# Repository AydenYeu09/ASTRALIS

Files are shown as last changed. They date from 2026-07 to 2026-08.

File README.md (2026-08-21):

# ASTRALIS

**ASTRALIS** is a thrust-vectoring aerial manipulation research quadcopter designed to investigate how independently vectored thrust can compensate for disturbances induced by the movement of an onboard robotic arm. 

ASTRALISv2_2026-Aug-08_04-18-19AM-000_CustomizedView49024496437

[ASTRALIS Public Onshape](https://cad.onshape.com/documents/e7aa6cff1a0b3da1907f913a/w/77e9de90cc715c4e64e50337/e/d9e24aa74ee5dafe20d41019)

## Research Goals
Aerial manipulators, while adding functionality and expanding the applicable scope of a quadcopter, introduce a major problem to multirotor flight: moving an arm and payload changes the vehicle's mass distribution and produces additional forces and moments on the aircraft. 
Conventional quadcopter s attempt to compensate for these disturbances primarily by changing the thrust produced by each motor. ASTRALIS adds another control input by allowing the motors themselves to tilt and change the direction of their thrust. 
The primary question I want to investigate is:
> **To what extent can independently vectored thrust reduced attitude disturbances caused by the movement of an aerial manipulator and its payload?**
ASTRALIS is designed specifically as a testbed to investigate this question through repeatable arm-disturbance experiments during flight.
---
## Design
ASTRALIS consists of three main subsystems: 
- A custom quadcopter airframe (carbon fiber machined top and bottom plates + cf nylon frame pieces)
- Four independently tilting motor pods
- A multi-jointed robotic manipulator

A **Pixhawk 6C Mini** handles flight control and stabilization, while a **Raspberry Pi 4 Model B** acts as the companion computer for running and logging experimental routines, telemetry collection, and future software uses.

### Thrust-Vectoring Pods
Each motor is mounted to a tilting pod actuated by a servo and pushrod linkage. This allows the direction of each motor's thrust to be changed independently. The current design establishes the pod pivot, servo type and location, and general linkage architecture. The final linkage dimensions, ball-end selection, and mechanical advantage calculations will be determined through physical prototyping. 

ASTRALISv2_2026-Aug-09_10-05-22PM-000_CustomizedView5219588414
ASTRALISv2_2026-Aug-09_10-07-08PM-000_CustomizedView10570838011_png

The design includes a dual flange-bearing supported pivot and shoulder bolt, mechanically linked by a threaded rod to a servo horn. This was chosen because the turning drone's motors during thrust action will induce gyroscopic force, and I want to ensure that the system is structurally sound. The mounts will be printed out of Nylon CF as it is the strongest available filament in my collection. 

### Aerial Manipulator 
ASTRALIS uses a multi-jointed robotic arm to manipulate payloads and generate controlled disturbances during flight. The arm is designed to use **Waveshare ST3215 serial bus servos**, allowing multiple joints to be controlled through the same communication bus. 
The arm was originally designed around DYNAMIXEL servos but was redesigned around the ST3215 to increase available torque while reducing the overall costs of the actuator and control system. 

>**Note: The arm will be 3D printed out of PLA**

ASTRALISv2_2026-Aug-09_10-07-26PM-000_CustomizedView5861968826_png

Payload capacity is being estimated by calculating the torque produced by each arm component and payload about its respective joints.



The calculated payload limits will be estimated once hardware is confirmed. 

---
## Electronics



The electronics are spread across flight control and experiment control. 

| Component | Details |
|---|---|
| Pixhawk 6C Mini | Main flight controller |
| Raspberry Pi 5 | Companion computer used for experimental control |
| M10 GPS  | Vehicle positioning |
| Pi Camera | Used for object pickup and capturing on-board footage |
| ST3215 Servos | Used for Robotic Arm  |
| PCA9685 | Tilt Servo Driver Board | 
| DS3230 | High Torque Tilt Servos (picked to handle gyroscopic forces from tilting the motors) |
| Hobbywing XRotor 3110 900KV | Thrust Motors |
| Blueson A2 4in1 65A ESC | ESC for XRotor 3110s|

---
## Software (derived from discontinued Urban-Gust-Optimized UAV) 
Software development is currently focused on establishing basic communication between the Raspberry Pi and the Pixhawk and building the framework required for arm-disturbance experiments. Once I have the hardware confirmed, I will delve into system-
Current code includes: 
- MAVLink initialization
- Heartbeat monitoring
- Vehicle State tracking
- Attitude and angular-rate data
- Battery telemetry
- GPS telemetry

Several of the modules are still under development and will be implemented as the corresponding hardware becomes available/confirmed for purchase.

---
## Experimental Plan
>**The following experiment is the current plan, but is subject to subtle changes as hardware is confirmed for purchase or rejected**

The initial experiment will measure the aircraft's response to repeatable robotic-arm movements. A standardized payload will be picked up by the manipulator and moved through a predetermined trajectory while vehicle telemetry is recorded.
Tests will eventually be performed for both **with and without thrust-vectoring compensation**.

After the results of this experiment, I will develop a prediction-based model in MATLAB that will account for non-predetermined arm movements. 

## Future Plans 
After determining the impact of thrust-vectoring vehicle stability, I plan to add more software capabilities to the drone, making it a fully fledged UAV. I want to explore more into computer vision driven tasks with the manipulator.

Measurements will include:
- Peak roll and pitch deviation
- RMS attitude error
- Angular velocity
- Settling time 
- Response across different payload masses 

This will allow the performance of the thrust-vectoring system to be compared against the aircraft's baseline performance.

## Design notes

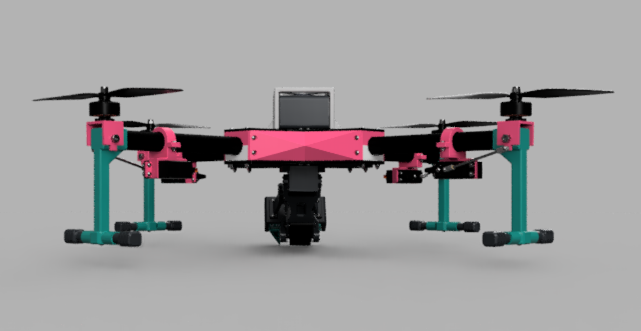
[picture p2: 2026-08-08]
Renders/Astralis_backRender.png

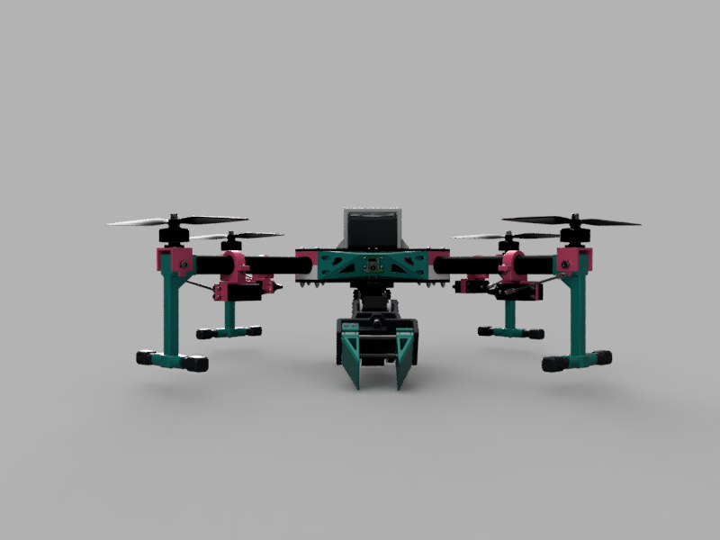
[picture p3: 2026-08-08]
Renders/Astralis_frontRender.png

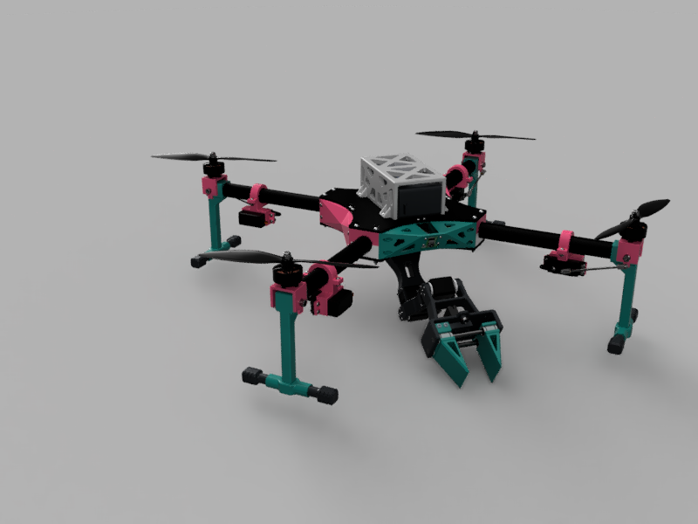
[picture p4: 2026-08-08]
Renders/Astralis_leftIso.png

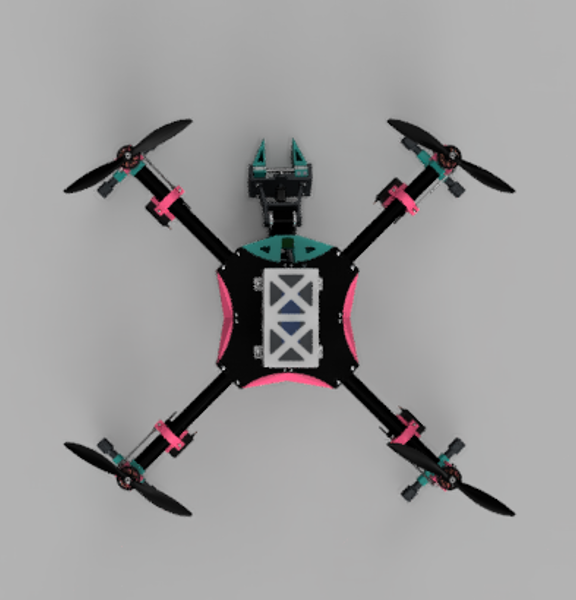
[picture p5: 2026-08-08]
Renders/Astralis_topRender.png

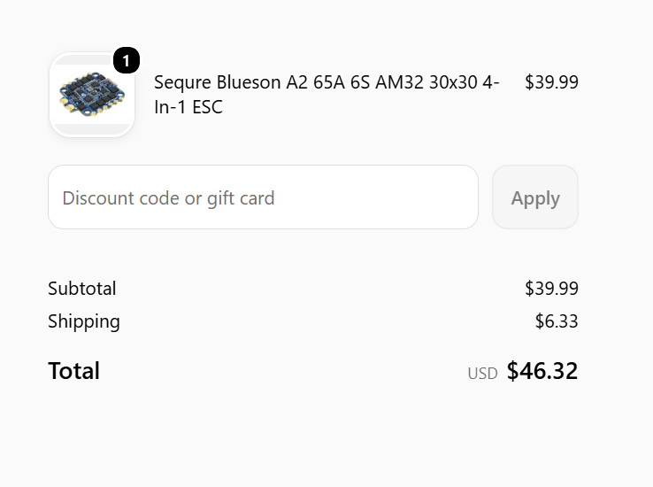
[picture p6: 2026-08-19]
Cart Shipping Screenshots/defiancerc.png

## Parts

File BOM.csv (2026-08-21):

Item | Category | Qty | Unit cost | Total cost | Vendor | Link | Status | Notes
Raspberry Pi 4 Model B | General Electronics | 1 | $0.00 | 0 | Raspberry Pi | https://www.raspberrypi.com/products/raspberry-pi-4-model-b/ | Already Owned | Already Owned
Pixhawk 6C Mini + PM06 | General Electronics | 1 | $0.00 | 0 | Holybro | https://holybro.com/products/pixhawk-6c-mini?variant=44511519539389 | Already Owned | flight controller, ease of access to telemetry, good interconnectivity with 4in1 esc, servo PWMS can connect to it
Sequre Blueson A2 65A 4in1 ESC | General Electronics | 1 | $39.99 | 39.99 | DefianceRC | https://www.defiancerc.com/collections/electronic-speed-control/products/sequre-blueson-a2-65a-6s-am32-4-in-1-esc | To buy
Ovonic Roam Series 6S Lipo Battery 6000mAh 6S1P 150C 22.2V Long Range Lipo Battery with XT90-S Anti Spark Plug for 7-10 inch Cinelifter Multirotor X-Class FPV Drone | General Electronics | 1 | $59.99 | 59.99 | OVONIC USA | https://us.ovonicshop.com/products/ovonic-roam-series-6s-lipo-battery-5500mah-6s1p-150c-22-2v-long-range-lipo-battery-with-xt90-s-anti-spark-plug-for-6s-cinel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 | To buy | factoring in $5 off $50+ discount
MECCANIXITY 304 Stainless Steel Round Rods, 6mm x 80mm Solid Shaft Rods for DIY Craft Model Car Helicopter Airplane, Pack of 5 | Aerial Manipulator | 1 | $9.99 | 9.99 | Amazon | https://www.amazon.com/MECCANIXITY-Stainless-Steel-Helicopter-Airplane/dp/B0DPH1PFTT | To buy
Pi Camera Module 3 | General Electronics | 1 | $0.00 | 0 | Amazon | https://www.amazon.com/Arducam-Raspberry-Camera-Module-IMX708/dp/B0G5YJMR8Q?sp_csd=d2lkZ2V0TmFtZT1zcF9hdGY | Already Owned
ACROPIX MR106ZZ Bearings Double Shielded Pre-Lubricated Deep Groove Ball Bearings 6x10x3mm Silver Tone - Pack of 10 | Aerial Manipulator | 1 | $7.49 | 7.49 | Amazon | https://www.amazon.com/ACROPIX-Bearings-Shielded-Pre-Lubricated-Deep-6x10x3mm/dp/B0C4PGLSCY | To buy
22mm x 20mm x 500mm Carbon Fiber Tube 2pc | Mechanical - Arm | 1 | $4.48 | 4.48 | AliExpress | https://www.aliexpress.us/item/2255800548281454.html?pdp_ext_f=%7B"order"%3A"4548"%2C"eval"%3A"1"%2C"fromPage"%3A"search"%7D&pdp_npi=6%40dis%21USD%218.80%215.10%21%21%218.80%215.10%21%402101ea8f17857353482108943e0d2f%2110000015285622328%21sea%21US%216211510477%21X%211%210%21n_tag%3A-29919%3Bd%3A782a1452%3Bm03_new_user%3A-29895%3BpisId%3A5000000212462172&curPageLogUid=WQxJ5C6ExckD&utparam-url=scene%3Asearch%7Cquery_from%3A%7Cx_object_id%3A4000734596206%7C_p_origin_prod%3A | To buy
4X DSServo Waterproof Servo (30Kg) | Rotor Tilt - Electronics | 1 | $52.78 | 52.78 | RCDrone | https://rcdrone.top/products/4x-waterproof-servo-20kg-25kg-30kg-35kg-40kg-high-speed-servo-pro-metal-gear-digital-servo-baja-servo-for-1-8-1-10-scale-rc-cars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 | To buy | MG996Rs are slower and not significantly cheaper —> having a heavier grade servo ensures that the force of gyroscopic precession won’t strip all the gears of the servo. also vendor has no shipping cost
Micro M10 GPS | General Electronics | 1 | $36.38 | 36.38 | AliExpress | https://www.aliexpress.us/item/3256807973728391.html?curPageLogUid=Nfn08dpLiBxy | To buy | Need for positioning and sensor for experiment
4PCS Hobbywing XRotor 3110/ Premium Brushless Motor - 900KV 4-6S M5 Shaft for 8-10" Heavy Lift FPV Drones | General Electronics | 1 | $81.60 | 81.6 | AliExpress | https://www.aliexpress.us/item/3256809458664696.html?pdp_ext_f=%7B"order"%3A"19"%2C"eval"%3A"1"%2C"fromPage"%3A"search"%7D&pdp_npi=6%40dis%21USD%21169.42%2183.02%21%21%211137.04%21557.15%21%402101d9ef17857369675166543e0f5f%2112000049988191307%21sea%21US%216211510477%21X%211%210%21n_tag%3A-29919%3Bd%3A782a1452%3Bm03_new_user%3A-29895&curPageLogUid=20aVGjfR1oiC&utparam-url=scene%3Asearch%7Cquery_from%3A%7Cx_object_id%3A1005009644979448%7C_p_origin_prod%3A | To buy
2pair HQProp 9x5x3 | Testing | 1 | $10.55 | 10.55 | AliExpress | https://www.aliexpress.us/item/3256808163754090.html?pdp_ext_f=%7B"order"%3A"141"%2C"eval"%3A"1"%2C"fromPage"%3A"search"%7D&pdp_npi=6%40dis%21USD%2120.23%2110.72%21%21%21135.78%2171.96%21%402101e81117857374162586296e0fc7%2112000044691697503%21sea%21US%216211510477%21X%211%210%21n_tag%3A-29919%3Bd%3Af6a29556%3Bm03_new_user%3A-29895&curPageLogUid=giSY8NM4Eluz&utparam-url=scene%3Asearch%7Cquery_from%3A%7Cx_object_id%3A1005008350068842%7C_p_origin_prod%3A | To buy
M3x8 Plastites (pk of 50) | Fasteners | 2 | $7.42 | 14.84 | McMaster | https://www.mcmaster.com/99461A941/ | To buy
M3x50mm Socket Partially Threaded | Fasteners | 1 | $5.65 | 5.65 | McMaster | https://www.mcmaster.com/91292A026/ | To buy | Arm tube clamps
M3 locknuts (pk of 100) | Fasteners | 1 | $4.29 | 4.29 | Amazon | https://www.amazon.com/Hordion-100Pcs-Stainless-Locknuts-Non-Slip/dp/B0CX16JZ6Z | To buy
Stainless Steel m4 thread, 5mm x 30mm (pk of 8) | Fasteners | 1 | $9.99 | 9.99 | Amazon | https://www.amazon.com/MECCANIXITY-Stainless-Hydraulic-Injection-Industries/dp/B0FDPX976R | To buy
MF95zz Bearing (5mm ID, 9mm OD) - pk of 10 | Fasteners | 1 | $9.49 | 9.49 | Amazon | https://www.amazon.com/uxcell-Bearing-5x9x3mm-Shielded-Bearings/dp/B085D7WFBR | To buy
Waveshare ST3215 Servo Motor | Aerial Manipulator | 4 | $20.63 | 82.52 | Waveshare | https://www.waveshare.com/st3215-servo.htm | To buy | replaced dynamixel because they are cheaper and are precise enough.
Serial Bus Servo Control/Power Distribution Board | Aerial Manipulator | 1 | $4.99 | 4.99 | Waveshare | https://www.waveshare.com/product/bus-servo-adapter-a.htm | To buy
12S to 12V BEC | General Electronics | 1 | $5.05 | 5.05 | AliExpress | https://www.aliexpress.us/item/3256810372424874.html?pdp_ext_f=%7B"order"%3A"76"%2C"eval"%3A"1"%2C"fromPage"%3A"search"%7D&pdp_npi=6%40dis%21USD%2110.87%215.00%21%21%2172.94%2133.55%21%402101c28d17861703912206676e0f36%2112000053151968418%21sea%21US%216211510477%21X%211%210%21n_tag%3A-29919%3Bd%3Af6a29556%3Bm03_new_user%3A-29895&curPageLogUid=Yly6hpUVcbog&utparam-url=scene%3Asearch%7Cquery_from%3A%7Cx_object_id%3A1005010558739626%7C_p_origin_prod%3A | To buy
8-23V Input to 5V USBC Output BEC | General Electronics | 1 | $5.50 | 5.5 | AliExpress | https://www.aliexpress.us/item/3256808480645422.html?pdp_ext_f=%7B"order"%3A"602"%2C"eval"%3A"1"%2C"fromPage"%3A"search"%7D&pdp_npi=6%40dis%21USD%2111.91%212.72%21%21%2179.95%2118.25%21%4021030dcd17861703694924828e2255%2112000046156518282%21sea%21US%216211510477%21X%211%210%21n_tag%3A-29919%3Bd%3A782a1452%3Bm03_new_user%3A-29895%3BpisId%3A5000000214368806&curPageLogUid=rfv8wqtYsREv&utparam-url=scene%3Asearch%7Cquery_from%3A%7Cx_object_id%3A1005008666960 | To buy
Step Down BEC 5V (normal output) | General Electronics | 1 | $3.24 | 3.24 | AliExpress | https://www.aliexpress.us/item/3256810580944443.html?pdp_ext_f=%7B"order"%3A"114"%2C"eval"%3A"1"%2C"fromPage"%3A"search"%7D&pdp_npi=6%40dis%21USD%217.89%213.63%21%21%2152.94%2124.35%21%402101e81117863143204767761e0eed%2112000053441881891%21sea%21US%216211510477%21X%211%210%21n_tag%3A-29919%3Bd%3A782a1452%3Bm03_new_user%3A-29895&curPageLogUid=VkQ4012PO8G6&utparam-url=scene%3Asearch%7Cquery_from%3A%7Cx_object_id%3A1005010767259195%7C_p_origin_prod%3A | To buy
 |  |  | Subtotal | 448.81
 |  |  | Total Cost (with Shipping Fees and Taxes) | 500.77

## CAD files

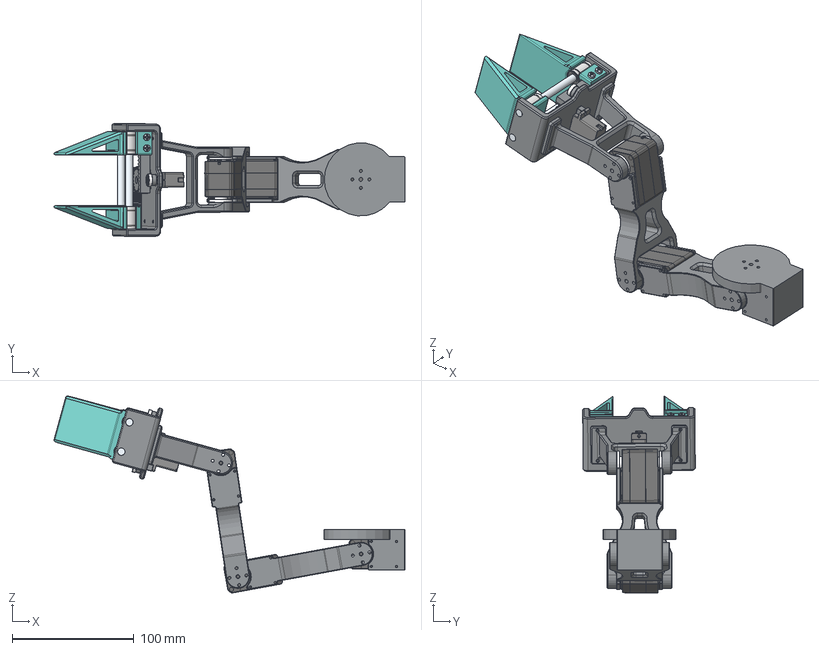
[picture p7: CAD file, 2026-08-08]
CAD Files/ASTRALIS - Arm/AARMv2.step
287.8 x 92.4 x 161.5 mm
GE_27:1__??1 x 3
SG-ZIJI_15:1__??1 x 3
???????? v2:1__??1 x 6
PCB-CHAZUO_92:1__??1 x 3
ZK_122:1__??1 x 3
MOTOR-1723_3:1__??1 x 3
XG-ZIJI_16:1__??1 x 3
wrist
base joint
Ligament 2
�г�-��ת1 x 2
Բ��2 x 2
����(Բ��)1[4] x 2
Rack (16 teeth) x 2
��ת4[2] x 2
����(Բ��)1[9] x 2
����(Բ��)1[8] x 2
����(Բ��)1[1] x 2
rod x 2
Shaft
PH Pan head screw M3x0.50 x 6 x 4
��ת2 x 2
Socket button head screw M2x0.4 x 8
main housing
����(Բ��)1[6] x 2
��ת4[1] x 2
����(Բ��)1[5] x 2
/private/var/mobile/Containers/Data/Application/CE62752C-AD6F-4AF3-94 70-06643F6F38D5/tmp/5A85296E-EDAF-43B4-99FA-8EC373BC8470.tmp x 4
����(Բ��)1[3] x 2
module x 2
����(Բ��)1[2] x 2
Spur gear (20 teeth)
����(Բ��)2 x 2
����(Բ��)1[7] x 2

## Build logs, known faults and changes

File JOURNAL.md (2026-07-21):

# Astralis: An Overactuated Aerial Manipulation Quadcopter

> **Note:** Built for Hack Club's Stardance Program and intended to serve as an MIT Maker Portfolio project.

---

# 2026-06-29 — Project Initialization

### Derived from the Urban Gust Optimized UAV Project

**Astralis** originated from my previous **Urban Gust Optimized UAV (UGOUAV)** project. The following resources were carried over:

- Top and bottom plate CAD
- Initial arm design
- Onshape CAD document
- Notion workspace
- Bill of Materials (BOM)

Although the projects share a common starting point, they have completely different objectives. **UGOUAV** has been officially retired and will no longer receive updates.

---

# 2026-06-30 — Devlog 1: Battery Holder V1 & Electronics Diagram

### Battery Holder V1

Designed the first iteration of the battery holder.

Features:
- Intended to be 3D printed in PLA.
- Battery slides into a dedicated slot.
- Future revision will include a retaining mechanism to securely hold the LiPo during flight.

### Electronics Diagram

Created the first draft of the electronics architecture using **Lucidchart** for compatibility with Notion.

This diagram outlines the major onboard components and serves as the foundation for future wiring and power distribution planning.

**Time Spent:** **2.5 hours**

### Images



---

# 2026-07-01 — Devlog 2: Servo Pod Research & Implementation

Focused primarily on designing the **servo pod**, a 3D printed component that mounts the tilt servo parallel to each thrust-vectoring pod.

The current design is inspired by the clamping mechanism presented in the following research paper:

> https://www.mdpi.com/2218-6581/7/4/65

The pod uses a shaft-collar style clamp that grips the carbon fiber arm while providing a rigid mounting point for the servo.

Future iterations will incorporate a pushrod linkage connecting the servo horn to the tilting motor pod.

### Next Steps

- [ ] Begin designing the aerial manipulator subsystem.
- [ ] Implement the pushrod linkage in CAD.
- [ ] Continue refining the thrust-vectoring mechanism.

**Time Spent:** **2 hours**

### Images


---

# 2026-07-04 — Devlog 3: *Aerial Manipulator CAD*!

Today, I completed the **body frame** of the drone with the addition of a Pi Camera Module 2 mount; I also worked on improving the battery holder design, this time ensuring it can be added and removed without extreme disassembly.

## Cool Things:

- I tinkered around with the “Convex Polyhedron” OnShape featurescript to make the drone’s body have a low poly aesthetic
- Added Colors!

## Main Things:

- I developed the **Pi Camera Mount**, having the mount protrude outwards from the X-wing configuration and angle thirty degrees downward.
  - The Pi Camera was added because it provides future upgrade possibilities regarding software decisions, as well as gives the opportunity to get some footage of the drone (I also had two Pi Cams in my stash)
  - There was lots of experimentation regarding this part. I tried using lofts to make the camera mount first and then loft outwards, but frustratingly I was not able to get the geometry to work (too tight of geometry to be lofting like that!)
  - I ended up using the Convex Polyhedron Featurescript, which allowed me to select a few points and enclose an area with a low-poly extruded body, which I then hollowed out to create more overflow space for wiring
  - I finally added some material pockets, mainly for aesthetics. I will need to evaluate the printability of this part and the pockets will be the first thing to be edited if it bars printability.
- The **battery holder** received minor improvements regarding tolerances and the addition of the closer arm, which is mounted by two screws on each side
  - I added more space for the battery
- The spacing between the **top and bottom plates** received an update, increasing 10mm so that a Dynamixel XL430 can fit within the drone’s frame (for the design of the manipulator)
  - This also resulted in the arm tube clamp being changed

## Next Things to Do:

- [ ] Start Arm/Manipulator Development
- [ ] Finish Tilt Pods (add m2 push rods)
- [ ] Update the BOM

**Time Spent:** **4 hours**

### Images 





---

# 2026-07-10 — Devlog 4: Aerial Manipulator Design

Over the past couple of days, I completed the **aerial manipulator** — the robot arm — for the drone. The current design assumes the use of **DYNAMIXEL XL430 and XL330 servos**, though the final servo mounting is not fully finalized in CAD yet.

## Cool Things

- The arm is **animated in CAD**
- The full manipulator is now integrated into the drone assembly
- I designed and compared **two different gripper concepts**

## The Arm

The arm uses **DYNAMIXEL smart servos** because they provide positional feedback and include many features that may be useful later.

The current manipulator is a **4-DOF robotic arm with a gripper**:

- **Base rotation** about the Z-axis
- **Shoulder rotation** about the X-axis
- **Elbow rotation** about the X-axis
- **Wrist rotation** about the X-axis
- **Servo-driven gripper** as the end effector

The arm is intended to be **fully 3D printed**, allowing for fast iteration and easier replacement of parts if the design changes.

## The Gripper

The bulk of the time was spent on the gripper, partly because I designed two different models:

1. A **linkage gripper**
2. A **standard parallel gripper**, inspired by this guide: [3D Printed Parallel Gripper for Robotic Arms](https://www.instructables.com/3D-Printed-Parallel-Gripper-for-Robotics-Arms/)

### Linkages…

The linkage gripper was designed with compactness in mind. It used a gear-driven linkage system and was intended to use **TPU fingers** to grip rigid payloads.

However, maintaining printing tolerances and designing around the linkage geometry made the CAD extremely messy. The mechanism had too many small pivot points, tolerance-sensitive parts, and potential failure points. Because of that, I could not justify printing and prototyping this version.

The main focus of the project is not the gripper itself. The focus is on testing how the drone handles **disturbances induced by arm movement and held payloads**. Because of this, I need full confidence that the gripper will work reliably without spending too much project time reprinting and redesigning it.

### Parallel Gripper!

Following the Instructables guide, I designed a simpler parallel gripper using a similar bearing, rod, and rack-and-pinion layout.

This gripper uses:

- A 3D-printed main body
- Rigid 3D-printed fingers instead of TPU fingers
- Two identical gear racks
- A central pinion gear
- Linear rods for jaw guidance

The CAD design was much simpler, and I am more confident that this version will produce reliable performance. The parallel gripper should be easier to print, easier to assemble, and easier to debug than the linkage gripper.

## Next Things to Do

- [ ] Add push/pull rods in CAD to the tilting pods
- [ ] Finalize internal electronics mounting
- [ ] Evaluate costs for plates and add weights in CAD
- [ ] Bias the center of gravity toward the ideal location
- [ ] Research and add drone motors and propellers to the BOM
- [ ] Add the DYNAMIXEL XL330 mount in the arm

**Time Spent:** **6 hours, 45 minutes**

### Images





---

# 2026-07-21 — Devlog 5: *Aerial Manipulator Finalized, Tilt Pods Finished, and Frame Finished*

Over the past few days, I finalized the overall airframe, completed the aerial manipulator, and finished the design of the thrust-vectoring tilt pods. This was probably one of the toughest and most detailed-focus stages of the project so far (definitely stayed up super late fixing it sometimes!), prompting several redesigns to accommodate the Dynamixel XL330-M288-T servos while also standardizing hardware throughout the drone.

> **Note:** I have another CAD timelapse recorded in Lookout that I'm still trying to transfer into Stardance.

---

## General Design Updates

A major focus during this stage was reducing complexity and improving ease of assembly.

- Standardized as many fasteners as possible across the drone.
- Reused hardware from previous combat robotics and robotics projects whenever practical.
- Organized the CAD assembly by separating self-tapping screws into dedicated **PLASTITES** folders while leaving machine screws in the default folders to simplify the assembly process.

---

## Landing Gear

The landing gear went through two complete design iterations.

The original concept used a dedicated clamp that attached independently to the carbon fiber arms. After evaluating the design, I integrated the landing gear directly into the arm end cap instead.

This redesign:

- Reduced the total number of printed components.
- Increased the distance between the landing feet, improving stability.
- Maximizes operating space of arm.
- Minimized interference with the thrust-vectoring pod geometry.

Each landing gear assembly consists of three printed components, including TPU feet intended to improve grip and absorb landing impacts.

---

## Tilt Pods

The thrust-vectoring pods are now mechanically complete.

The largest addition during this stage was designing the pushrod linkage connecting each servo horn to its corresponding tilt pod. 
At the moment:

- The linkage geometry has been finalized.
- The linkage components will be 3D printed and prototyped.
- Mechanical advantage calculations and linkage calibration still need to be completed before the CAD animation accurately reflects the pod motion.

---

## Aerial Manipulator

The aerial manipulator has now been finalized (closed book, finally done!).

One of the largest changes was redesigning the arm to properly mount the Dynamixel XL330-M288-T servos internally instead of externally.

Benefits of the redesign include:

- Cleaner overall appearance.
- More compact packaging.

The servos will be mounted using the provided M2 self-tapping screws directly into the printed components.

---

## Battery Holder V2

The battery mounting system also received a significant redesign.

Originally, the battery was positioned underneath the frame because I assumed lowering the center of gravity would improve stability. After learning more about quadcopter dynamics, I realized this configuration introduces a pendulum effect that complicates flight control.

The updated design mounts the battery on top of the frame using a PLA battery cradle secured with four M4 machine screws and a Velcro strap.

This redesign also frees the entire underside of the frame for the aerial manipulator, allowing the arm to rotate through a full **360°** without the battery obstructing its workspace.

---

## Next Steps
- [ ] Assign materials to all CAD components and calculate the drone's center of gravity.
- [ ] Finalize the complete electrical component placement within the body and wiring diagram.
- [ ] Characterize the thrust-vectoring linkage and determine its mechanical advantage.
- [ ] Begin firmware development and hardware testing routines.
- [ ] Write assembly documentation and build guides.
- [ ] Begin printing and validating mechanical prototypes.

**Time Spent:** **6 hours, 45 minutes**

### Images





---

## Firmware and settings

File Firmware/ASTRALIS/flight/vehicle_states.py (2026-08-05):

#stores all relevant information to the drone (hence, a vehicle state)

#8/4 - disabling GPS for now.
class VehicleState:
    def __init__(self):
        #Connection Status 
        self.connected = False
        self.armed = False 
        self.flight_mode = "UNKNOWN"

        #IMU
        self.roll = 0.0 
        self.pitch = 0.0
        self.yaw = 0.0 

        #IMU Derivatives 
        self.roll_rate = 0.0
        self.pitch_rate = 0.0 
        self.yaw_rate = 0.0

        #Battery 
        self.battery_voltage = 0.0
        self.battery_current = 0.0 
        self.battery_remaining = 0.0

        #GPS 
        # self.latitude = 0.0
        # self.longitude = 0.0
        # self.altitude = 0.0

        # self.ground_speed = 0.0
        # self.heading = 0.0 

    def print_status(self): 
        print(f"Connected: {self.connected}")
        print(f"Mode: {self.flight_mode}")
        print(f"Armed: {self.armed}")


        print(f"Roll: {self.roll:.2f}")
        print(f"Pitch: {self.pitch:.2f}")
        print(f"Yaw: {self.yaw:.2f}")

        # print(f"Latitude: {self.latitude:.3f}")
        # print(f"Longitude: {self.longitude:.3f}")
        # print(f"Altitude: {self.altitude:.2f} m")

        print(f"Battery: {self.battery_voltage:.2f}V")
              

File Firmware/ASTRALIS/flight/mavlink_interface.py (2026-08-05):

import math
import time 


from pymavlink import mavutil

from vehicle_states import VehicleState 


class MavlinkInterface:
    def __init__(self, connection_address, baud_rate=57600):
        self.connection_address = connection_address
        self.baud_rate = baud_rate

        self.connection = None 
        self.state = VehicleState()

        #heartbeat vars
        self.last_heartbeat_time = 0.0 
        self.heartbeat_timeout = 5.0 

    def connect(self):
                print(f"Connecting to MAVLINK at {self.connection_address}...")
    
                try:
                    self.connection = mavutil.mavlink_connection(
                        self.connection_address,
                        baud = self.baud_rate
                    )
    
                    print("Waiting for Pixhawk heartbeat...")
    
                    heartbeat = self.connection.wait_heartbeat(
                          timeout=10
                          )
    
                    if heartbeat is None:
                        print("Connection failed: no heartbeat received :(")
                        return False
    
                    self.state.connected = True
                    self.last_heartbeat_time = time.monotonic() #this might be the wrong time referencing

                    print("Pixhawk connected!")

                    return True

                except Exception as error: 
                    print(
                         f"MAVLink connection failed: {error} :("
                    )

                    return False

    def update(self):
        if self.connection is None:
            return
        message = self.connection.recv_match(
            blocking=True,
            timeout=0.2
        )

        if message is None:
            self.check_connection()
            return

        if message.get_type() == "BAD_DATA":
              return

        message_type = message.get_type()

        if message_type == "HEARTBEAT":
              self.update_heartbeat(message)

        elif message_type == "ATTITUDE":
              self.update_attitude(message)

        elif message_type == "BATTERY_STATUS":
             self.update_battery(message)

        # elif message_type == "GPS_RAW_INT": #noisy data
        #      self.update_gps(message)

        elif message_type == "GLOBAL_POSITION_INT": #EKF and Fused Data for GPS/IMU 
            self.update_position(message)

        def update_heartbeat(self, message):
            self.last_heartbeat_time = time.monotonic()    
            self.state.connected = True 

            armed_flag = (
                 mavutil.mavlink.MAV_MODE_FLAG_SAFETY_ARMED
            )

            self.state.armed = bool(
                 message.base_mode & armed_flag
            )

            self.state.flight_mode = (
                 self.connection.flightmode
            )

        def update_attitude(self, message):
             #MAVLink uses radians
             # Converting to degrees (for personal preference) 

            #IMU dofs 
            self.state.roll = math.degrees(message.roll)  
            self.state.pitch = math.degrees(message.pitch)
            self.state.yaw = math.degrees(message.yaw)

            #IMU rates 
            self.state.roll_rate = math.degrees(message.rollspeed)
            self.state.pitch_rate = math.degrees(message.pitchspeed)
            self.state.yaw_rate = math.degrees(message.yawspeed)

        def update_battery(self, message):
            # millivolts -> volts 
            self.state.battery_voltage = (
                 message.voltage_battery / 1000 #volt conversion factor
            )

            # centiamps -> amps 
            self.state.battery_current = (
                 message.current_battery / 100 
            )

            self.state.battery_remaining = ( 
                 message.battery_remaining
            )


        def update_posiiton(self, message):
             #degrees * 10^-7 -> degrees (mavlink is WEIRD!)
            self.state.latitude = (
                message.lat / 10000000
            )

            self.state.longitude = (
                message.lon / 10000000
            )

            self.state.altitude = (
                message.alt / 10000000
            )

        def check_connection(self):
            time_since_heartbeat = (
                 time.monotonic() - self.last_heartbeat_time
            )

            if time_since_heartbeat > self.heartbeat_timeout: #connection timed out condition
                 self.state.connected = False

                 print(
                      "Lost MAVLink connection :("
                 )
                 return False
            return True

        def close(self):
            if self.connection:
                  self.connection.close() 
                  self.connection = None 

            self.state.connected = False 
            print("MAVLink is disconnected.")

    
             





             
  

            

         
       

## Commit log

2026-07-21 Journal Updates From June 30th 2026 to Current. Imported from Stardance.
2026-08-05 base commit, mavlink_interface (listener) and vehicle_states preliminary code done, pivoting over to working camera stream and other files.
2026-08-08 Renders and CAD Files added
    [AARMv2.step]
2026-08-09 Added BOM
    [ASTRALIS_BOM.csv]
2026-08-09 Update README.md with 3D printing info
2026-08-09 new BOM
    [ASTRALIS_BOM.csv]
2026-08-19 Eject BOM from README until fixed
2026-08-21 Updated BOM and Fixed for Stardance Resubmission
    [ASTRALIS_BOM.csv, BOM.csv]
